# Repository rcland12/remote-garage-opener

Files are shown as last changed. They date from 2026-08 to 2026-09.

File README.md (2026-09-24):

# Remote garage door controller

Adds remote operation to a Linear garage door opener using an ESP32-S3 and an
optocoupler relay. The relay momentarily bridges the opener's pushbutton
terminals, exactly like pressing the wall button.

There is no door sensor. This is a remote wall button: it presses, and that is
all it does. It cannot tell you whether the door is open or closed, and it
does not pretend to. Use a camera in the garage for that, and look at it
before you press.

The device is LAN only. Reaching it from outside the house is a separate
service's job, and it is in this repo: `server/` is a small Python API that
holds the device token, authenticates every caller, and makes the LAN-local
call to the ESP32. Nothing routes to the controller from the internet.

That server runs on **Linux, macOS or Windows**, on whatever machine you
already leave switched on - a Raspberry Pi, a NAS, a mini PC, the old laptop
in the closet. It is one Python file with one optional dependency. There is a
Docker Compose stack, and a native install for each of the three platforms.
See `server/README.md`, and `docs/remote-access.md` for how to reach it from
outside.

## Quick start

    # 1. configure
    cp firmware/secrets.example.py firmware/secrets.py
    python3 -c "import secrets; print(secrets.token_urlsafe(32))"
    $EDITOR firmware/secrets.py

    # 2. flash MicroPython, then deploy       (docs/flashing.md)
    ./tools/deploy.sh --reset

    # 3. wire it up                            (docs/hardware.md)

    # 4. drive it
    export GARAGE_HOST=garage.home.arpa GARAGE_TOKEN=...
    ./tools/garage.py status
    ./tools/garage.py toggle

    # 5. optional: reach it from outside the house  (server/README.md)
    cd server && cp garage-api.env.example garage-api.env
    $EDITOR garage-api.env
    docker compose up -d --build

`DRY_RUN` in `firmware/config.py` gates whether the relay pin is driven at all.
It is currently `False`, because this build is commissioned and moving a real
door. Set it back to `True` before any bench work: with it on, `POST /toggle`
only writes a log line and the pin is never configured, so you can exercise
the whole API with the relay wired and nothing will move.

## API

The device's own API. The server in `server/` puts the same commands one hop
further out, namespaced under `/garage`, behind a credential you can revoke.

| Method | Path | Auth | Result |
|---|---|---|---|
| GET | `/health` | no | liveness, uptime |
| GET | `/status` | no | moving hint, uptime, RSSI, IP, reset cause |
| GET | `/log` | no | recent events from the in-memory ring buffer |
| POST | `/toggle` | yes | pulse the relay for 500 ms |

There is deliberately no `/open` or `/close`. Without a door sensor the device
cannot distinguish an open door from a closed one, so a "close" command would
be a coin flip that opens the garage half the time. One button, the same one
that is on the wall. Both paths return 404.

The `moving` field in `/status` is a timer counting down `TRAVEL_MS` from the
last pulse, not a measurement. It means "we pulsed recently, so the door is
probably still travelling." It is not evidence the door moved at all.

Auth is a shared secret in the `X-Auth-Token` header, compared in constant
time. Everything returns JSON with an `ok` field.

    curl -X POST -H "X-Auth-Token: $GARAGE_TOKEN" http://$GARAGE_HOST/toggle

A second pulse inside the cooldown window returns 429 rather than reversing a
door that just started moving.

## The server

`server/` is the other half of the build: a small API that fronts the device
so you can reach the door from outside the house without exposing anything.
It holds the device token, authenticates every caller, applies a per-caller
scope and a cooldown, and then makes the one LAN call the device understands.

    phone / laptop
      -> https://api.example.com/garage/toggle
      -> Cloudflare Access                  service token policy, at the edge
      -> cloudflared -> the server          on a machine in your house
      -> http://192.168.1.50/toggle         X-Auth-Token, LAN only
      -> the relay closes for 500 ms

**It runs anywhere.** One Python file, standard library only unless you use
Cloudflare Access, which adds PyJWT. Point it at a machine that stays on and
is on the same LAN as the ESP32 - a Raspberry Pi, a NAS, a mini PC, a desktop,
the laptop with the cracked screen. Pick an install:

| | Docker | Native |
|---|---|---|
| **Linux** | `docker compose up -d --build` | systemd unit, `sudo ./install/install-unix.sh` |
| **macOS** | Docker Desktop, same command | launchd daemon, same install script |
| **Windows** | Docker Desktop, same command | Scheduled Task, `.\install\install-windows.ps1` |

The native installs run at boot with no user logged in, which Docker Desktop
on macOS and Windows does not. On Linux either is fine.

Two ways to reach it, chosen with `AUTH_MODE`:

- **`access`** - a Cloudflare Tunnel and an Access service token policy. A
  real HTTPS URL with nothing port forwarded, and the only option an iPhone
  Shortcut can use, because a Shortcut cannot bring up a VPN first.
- **`token`** - no Cloudflare at all. Reach the machine over Tailscale,
  WireGuard or an SSH forward, and the server checks a bearer key per client
  on top of that.

| Method | Path | Result |
|---|---|---|
| POST | `/garage/toggle` | pulse the relay |
| POST | `/garage/selftest` | the same path, no pulse |
| GET | `/garage/status` | the device's status |
| GET | `/garage/log` | the device's event ring |
| GET | `/garage/audit` | who has pressed the button |
| GET | `/service/actions` | what these credentials may call |

Setup, per-OS notes, the Cloudflare dashboard steps and the iPhone Shortcut
recipes are all in `server/README.md`.

## Safety properties

These are the invariants the build is made of. Changing any of them should be
a deliberate decision, not a side effect of something else.

In the firmware:

- The relay pin is idle at boot, after a crash, and after a watchdog reset.
  It is initialised with `Pin(..., value=idle)` so there is no window where
  it is driven active.
- The relay only ever pulses. `Relay.poll()` releases it from the main loop;
  no code path can latch it on.
- GPIO 5 is a plain GPIO. Strapping pins 0, 3, 45 and 46 are never used.
- A hardware watchdog reboots a wedged board. The reboot cannot move the door.
- The only electrical connection to the opener is the isolated dry contact.
  Nothing touches the opener's 28 V supply.

In the server:

- `API_SCOPES` is deny by default, and empty is a fatal boot error. There is
  no safe permissive default for something that opens a garage door.
- `GARAGE_TOKEN` unset is deliberately not fatal. The service boots, the
  read-only routes work, and `/garage/toggle` refuses with a 502. Failing
  closed for a door means refusing to move it, not refusing to start.
- Nothing proxies a request through to the device. `device_call` hand-builds
  one with a single header, because the firmware's `MAX_REQUEST_BYTES` is
  2048 and a tunneled request is larger than that. Calls are serialised; the
  device serves one connection at a time.
- The device token never leaves the machine the server runs on. Clients hold
  a credential that can be revoked from a dashboard instead.
- The process is unprivileged, read-only, no volumes, no host paths, no
  capabilities. Every action it takes is one outbound HTTP call.

## Layout

    firmware/     MicroPython: config.py, garage.py, main.py, secrets.example.py
    server/       app.py             the API that fronts the device
                  run.py             start it from an env file, any OS
                  README.md          install, Cloudflare setup, troubleshooting
                  garage-api.env.example  every setting, with the reasoning
                  compose.yml        docker, with an optional cloudflared
                  Dockerfile         unprivileged, read-only, no volumes
                  install/           systemd, launchd, Windows scheduled task
                  cloudflared/       tunnel config example
    tools/        deploy.sh          push firmware to the board over USB
                  deploy.py          the same, cross-platform, and it names
                                     the UART bridge port by vendor id
                  garage.py          full client for both APIs: status, log,
                                     audit, actions, selftest, toggle, watch
                  toggle.sh          one-shot pulse, nothing else
                  verify_remote.sh   check the Cloudflare Access path end to end
                  smoke_test.sh      exercise every device endpoint
                  smoke_test.py      the same, without curl or bash
                  simulate.py        run the firmware on a desktop, no hardware
    docs/         hardware.md, flashing.md, remote-access.md
    enclosure/    build_enclosure.py  parametric Fusion 360 model, source of truth
                  *.stl               exported base and lid
    article/      medium-article.md   the writeup, not part of the build
                  medium-draft.md     the outline it came from
                  assets.md           shot list and pre-publish checklist

The `.py` tools are there so the build can be followed from Windows, where
neither bash nor curl is a given. They are standard library only and behave
identically to their shell counterparts; `garage.py` and `simulate.py` already
ran anywhere. Two implementations of the same check can drift, so if the shell
versions stop earning their keep, the Python ones are the better survivors.

## Testing without hardware

`tools/simulate.py` runs the real firmware on a desktop against stub hardware,
so the API, the auth path and the 500 ms pulse can all be exercised before the
parts are wired.

    ./tools/simulate.py --port 8099
    GARAGE_HOST=127.0.0.1:8099 GARAGE_TOKEN=simulator-token ./tools/smoke_test.sh --pulse

## Status

Deployed and in service. The controller sits on top of the opener's motor head
in its printed enclosure, wired to the `PUSHBUTTON` and `COMMON` terminals, and
moves the door on request.

Verified on the hardware, not just in simulation:

- 11/11 endpoint checks pass against the device
- Relay module is active HIGH; `RELAY_ACTIVE_HIGH = True`
- A 10k pull-down on GPIO 5 holds the relay off through the window between
  power-on and MicroPython configuring the pin. Confirmed silent across
  repeated resets and cold power-cycles, which is the test that matters
- Contact closes for roughly 500 ms per pulse, measured on a meter
- WiFi sits at -18 to -32 dBm in its installed position

Remote access is the Cloudflare Access path in `docs/remote-access.md`, served
by `server/` and driven from an iPhone Shortcut.

Outstanding: the enclosure has been revised since the installed one was
printed. The current STLs add a 180 degree ESP32 rotation so the USB ports
clear their guide wall, a wider and taller USB opening, a lid grip tongue, and
a looser slide fit. Reprint both parts when convenient; nothing is wrong with
the installed one.

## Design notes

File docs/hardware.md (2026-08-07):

# Hardware assembly

Build and wiring instructions for the remote garage controller. Work through
the steps in order. Steps 1 through 4 happen at a desk with nothing connected
to the opener, so a mistake costs you nothing.

## Safety

Read this once before starting.

- A garage door is the heaviest moving object in a house. It can injure a
  person or crush a car roof. Everything below assumes the opener's photo-eye
  safety sensors are installed and working. Test them before you commission
  this: wave a broom through the beam while the door is closing and confirm
  the door reverses. If it does not reverse, fix that before adding remote
  control.
- Unplug the opener from its ceiling outlet before touching its terminal
  screws. The motor and light circuit are line voltage.
- Operating a door you cannot see is the real risk this project introduces,
  and this build has no door sensor at all. It cannot tell you whether the
  door is open, let alone whether someone is standing in the doorway. A camera
  pointed at the garage is not optional here; it is the only feedback you get.
  Look at it before every remote operation.
- Nothing in this build connects to the opener's 28 V accessory supply. The
  only electrical connection to the opener is the isolated relay contact
  across the two pushbutton terminals.
- Route the low-voltage wiring away from the door's moving parts, the
  counterbalance springs and the chain or belt.

## Parts

| Item | Notes |
|---|---|
| ESP32-S3 dev board | Powered by USB from a 5 V phone charger |
| 1-channel relay module | 3.3 V trigger, optocoupler isolated, 3 V coil |
| Female-to-female Dupont jumpers | ESP32 to relay module, 3 needed |
| 470 uF electrolytic capacitor | Across relay VCC and GND, see step 2 |
| 16 AWG 2-conductor wire | Controller to opener terminals |
| USB cable and 5 V charger | Data-capable cable, you will flash over it |
| Multimeter | Needed for steps 2, 4 and 5. Not optional |
| Camera for the garage | Separate from this project, but do not skip it |

## Step 1: bench test the board, no relay attached

Flash MicroPython and the firmware first, following `docs/flashing.md`. Leave
`DRY_RUN = True` in `firmware/config.py` for now.

Power the board over USB, find its IP from the serial console, and confirm the
API answers:

    GARAGE_HOST=<ip> ./tools/smoke_test.sh

All read-only checks should pass. At this point `POST /toggle` only writes a
log line; the relay pin is never driven.

## Step 2: determine your relay module's trigger polarity

Most cheap optocoupler relay boards are active LOW: the relay energises when
IN is pulled to ground. Some are active HIGH. Get this right or the relay will
sit closed whenever the board is idle, which would hold the opener's button
down permanently.

With the relay module powered but its screw terminals connected to nothing:

1. Connect relay VCC to the ESP32 3V3 pin, relay GND to an ESP32 GND pin.
2. Leave relay IN disconnected. Note whether the relay's LED is on and whether
   you heard it click when power was applied.
3. Touch the IN pin briefly to GND. If the relay clicks in, it is active LOW.
4. Touch IN briefly to 3V3. If it clicks in, it is active HIGH.

Set `RELAY_ACTIVE_HIGH` in `firmware/config.py` accordingly.

Measured on this build: the module is a Songle SRD-03VDC-SL-C board with screw
terminal inputs rather than a pin header, and it is **active HIGH**. IN to 3V3
energises it, IN to GND does nothing. `RELAY_ACTIVE_HIGH = True` is set.

Active HIGH carries a boot risk that active LOW does not. Idle is a LOW pin,
but from power-on until MicroPython configures GPIO 5, that pin is an
undriven input and floats. A pin floating high is a relay clicking on boot,
which is a garage door opening during a thunderstorm. Step 4 tests for this
explicitly. If it fails, fit a 10k resistor from GPIO 5 to GND, which holds IN
low through the float window without affecting the firmware's ability to drive
it high.

While you are here, check the coil voltage printed on the relay can. Match the
supply to the coil; this goes wrong in both directions.

- Coil says 5 V: power VCC from the dev board's 5V (VBUS) pin, not 3V3, and
  leave IN on GPIO 5. The optocoupler input still triggers happily from 3.3 V.
  A 5 V coil on the 3V3 regulator will brown out the board.
- Coil says 3 V or 3.3 V: power VCC from 3V3. Do not "fix" a brownout by
  moving it to 5V, which puts roughly 65 percent over-voltage across a 3 V
  coil. See the capacitor note below instead.

A 3 V coil draws on the order of 100 to 150 mA while energised, and it pulls
that current in a step. The dev board's regulator can supply it, but the
inrush lands on the same 3V3 rail the radio uses. Fit a bulk capacitor,
100 uF or larger electrolytic, directly across the relay module's VCC and GND
pins, minding polarity. That is cheap insurance against a reset when the relay
fires and it costs nothing if the rail was fine anyway.

You do not need to add a flyback diode. These optocoupler modules already have
one across the coil, along with the driver transistor.

## Step 3: wire the relay to the ESP32

Unplug USB power first.

| ESP32-S3 pin | Relay module pin |
|---|---|
| 3V3 (or 5V, see step 2) | VCC |
| GND | GND |
| GPIO 5 | IN |

GPIO 5 is a plain GPIO on the ESP32-S3. Do not move the relay to GPIO 0, 3, 45
or 46. Those are strapping pins; they are sampled and can glitch at reset,
which would pulse the door every time the board reboots.

If your relay module has a separate JD-VCC jumper, leave the factory jumper in
place. That jumper is what shares the logic supply with the coil, which is
what you want for a single-supply build.

## Step 4: verify the pulse, still not connected to the opener

Set `DRY_RUN = False` in `firmware/config.py`, redeploy, and put a multimeter
in continuity or resistance mode across the relay's COM and NO screw
terminals. It should read open circuit.

Fire a pulse:

    GARAGE_HOST=<ip> GARAGE_TOKEN=<token> ./tools/garage.py toggle

You should hear one click, see the relay LED flash, and the meter should beep
for about half a second before going open again. Confirm all three:

- Exactly one click in, one click out. Never a latch.
- `GET /log` shows a single `relay_pulse` entry.
- Press the board's reset button. The relay must not click at all during
  boot. Do not proceed to step 5 until a reset is silent.
- Pull the USB cable and plug it back in. Same requirement: no click. A cold
  power-up is a different case from a reset button, because the 3V3 rail is
  ramping at the same time the pin is floating. Test both.

If a reset does click, this build is active HIGH and the cause is almost
certainly GPIO 5 floating before the firmware drives it. Fit a 10k resistor
between GPIO 5 and GND. It holds IN low through the float window and is far
too weak to interfere with the firmware driving the pin high afterwards.
Re-run both tests before continuing.

## Step 5: identify the opener's pushbutton terminals

Unplug the opener.

The Linear opener has a low-voltage terminal strip on the back or side of the
motor head, where the wall button wires land. Some Linear wall stations use
two wires, some use three (the third drives the light). You want the two
terminals that the existing wall button's switch contacts bridge.

Confirm with the multimeter before you connect anything:

1. Plug the opener back in. Do not touch the line-voltage side.
2. Measure DC voltage across the candidate pair. Expect something in the
   region of 5 to 24 V open circuit. This is the opener sensing an open
   switch.
3. If you measure around 28 V, you are on the accessory supply pair. Move off
   it. Nothing in this project touches that.
4. Have someone press the wall button, or briefly bridge the pair with a short
   jumper wire. The door should run. That confirms the pair, and it confirms
   that a dry contact is all the opener wants.

Unplug the opener again once you have identified the pair.

## Step 6: connect the relay to the opener

Run the 16 AWG two-conductor wire from the controller's location to the
opener's terminal strip. 16 AWG is far heavier than this signal needs, which
is fine; it just makes the screw terminals a little crowded.

| Relay screw terminal | Opener terminal |
|---|---|
| COM | one of the pushbutton pair |
| NO | the other of the pushbutton pair |

Polarity does not matter. This is a dry contact, exactly equivalent to the
wall button's own switch. Leave the existing wall button wired in parallel;
both will keep working.

Do not use the NC terminal. NC is closed at rest, which would hold the
opener's button pressed.

## Step 7: the camera

This build has no door sensor, so the API cannot tell you whether the door is
open or closed. A camera in the garage is what fills that gap, and it fills it
better than a reed switch would: it shows you the doorway, not just the door.

Set it up before you start operating the door remotely, not after. It does not
need to integrate with this project in any way. It needs to be something you
can pull up on your phone, in a second or two, from wherever you are.

The habit that makes this safe is: look, then press. A reed switch could never
have told you a bicycle was leaning in the doorway.

## Step 8: commissioning

1. Power the controller from the 5 V phone charger, not from a laptop.
2. Stand where you can see the door.
3. `./tools/garage.py status`, confirm the API answers.
4. `./tools/garage.py toggle`, confirm the door runs.
5. Let it finish. Confirm `moving` clears about 15 seconds later.
6. Reset the board while the door is closed. Confirm the door does not move.
7. Pull the charger and plug it back in. Confirm the door does not move, and
   that the API comes back on its own within about 30 seconds.

Steps 6 and 7 are the ones that matter. A controller that pulses the door on
power-up is a controller that opens your garage during a thunderstorm.

Then repeat step 4 once from outside the house, over the VPN, with the camera
up on your phone. That is the real workflow; run it once while you are still
close enough to walk back and fix things.

## Cable strain relief

Anchor both cables so a tug lands on a zip tie and not on a solder joint or a
Dupont pin: the USB cable and the pair going to the opener.

The printed enclosure has an anchor tab outside each cable exit, with a pair of
slots through it. Thread a tie up through one slot, over the cable, and down
through the other. Both tabs sit at the floor line, flush with the bottom face,
so they do not interfere with the adhesive strips.

Anchoring to a nearby joist or the opener's rail bracket also works, and is
worth doing as well as the tabs for the run to the opener terminals, which is
the longer and more exposed of the two.

## Troubleshooting

| Symptom | Likely cause |
|---|---|
| Relay clicks once at every boot | Trigger polarity wrong, or relay moved to a strapping pin. Recheck step 2 |
| Relay clicks but the door does nothing | Wrong terminal pair, or wired to NC instead of NO |
| Door runs twice per request | `PULSE_MS` too long for this opener, try 300 ms |
| `POST /open` returns 404 | Correct. There is no door sensor, so only `/toggle` exists. See the README |
| API unreachable after a few days | Check `GET /status` for `reset_cause`. `watchdog` means the loop wedged and recovered |
| Board reboots when the relay fires | Coil inrush is browning out the 3V3 rail. Add the bulk capacitor from step 2. Only move VCC to 5V if the coil is actually rated 5 V |

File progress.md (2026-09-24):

# Progress

State of the build. Written down because the useful parts are the decisions
and the measurements, not the code, and neither is recoverable from a diff.

## Where it is

Deployed and in service. The controller sits on top of the opener's motor
head, wired to the `PUSHBUTTON` and `COMMON` terminals, and moves the door.

## Firmware

Three files plus a secrets template, MicroPython 1.28.0 on an ESP32-S3.

- `main.py` - WiFi with auto-reconnect, HTTP API, one cooperative loop. The
  listening socket is polled with a 20 ms timeout so servicing the relay and
  the watchdog never waits on a client, and no client waits on a 500 ms pulse.
- `garage.py` - relay pulse state machine and the event ring buffer.
- `config.py` - pins, timings, `DRY_RUN`, relay polarity.

Four routes: `GET /health`, `GET /status`, `GET /log`, `POST /toggle`.

There is no `/open` or `/close`. There was, early on, and they read a reed
switch to decide whether to no-op. Both are gone along with the reed switch
itself. Without a sensor those endpoints can only guess, and a wrong guess on
`/close` opens the garage and leaves it open.

Worth knowing about the removal: with the reed switch gone but the endpoints
still present, `/open` would have returned `"ok": true, "action": "none"` and
never pulsed the relay, because the unconnected pin read as "already open"
forever. `tools/smoke_test.sh` only exercised `/toggle`, so it passed 9/9 while
`/open` was silently dead. The smoke test now asserts both paths return 404.

## Hardware

| Item | Value |
|---|---|
| Board | ESP32-S3 N16R8, 16 MB flash, 8 MB octal PSRAM |
| Bridge chip | CH343 (`1a86:55d3`), enumerates as `/dev/ttyACM0` |
| Relay | Songle SRD-03VDC-SL-C module, screw terminal inputs |
| Trigger polarity | **Active HIGH**, measured |
| Pull-down | 10k, GPIO 5 to GND |

Two things here cost real time and are worth remembering.

**The board has two USB-C ports, `COM` and `USB`.** Use `COM`. It is the UART
bridge, its DTR/RTS drive EN and GPIO 0, so esptool enters the bootloader on
its own and the port survives whatever the firmware does. Do not identify it
by device name: this board's CH343 is a CDC-class part, so `COM` appears as
`ttyACM0`, the same name native USB would use. Tell them apart by USB vendor
id, `1a86` for the bridge and `303a` for Espressif.

**The relay is active HIGH, which is the uncommon case.** Idle is therefore a
LOW pin, and between power-on and MicroPython configuring GPIO 5 that pin is
an undriven input that floats. A pin floating high is a relay clicking on
boot, which is a garage door opening during a thunderstorm. The 10k pull-down
exists for exactly that window. It was fitted before testing rather than after,
because whether a floating pin drifts high enough depends on temperature and
humidity, and passing three resets on a desk in July proves nothing about a
cold morning in January.

## Enclosure

Parametric Fusion 360 model, driven over an SSH tunnel through the fusion360
MCP bridge. `enclosure/build_enclosure.py` is the source of truth; it is
idempotent and rebuilds everything from its parameter table.

Both boards are retained by their edges, not screwed down: neither has usable
mounting holes. Rails support the PCB edges, guide walls locate them
laterally, and a sliding lid closes it.

Decisions that are not obvious from the geometry:

- **The ESP32 faces component-side down.** The Dupont wires must reach the
  pins, so the pins point up. The cost is that its LED, reset and BOOT buttons
  face the floor and are unreachable once assembled. Acceptable because
  flashing happens over `COM` with auto-reset.
- **The ESP32 is rotated 180 degrees** from the arrangement you would first
  reach for. The guide wall has to bear on one end of the board, and against
  the USB end it blocks the ports. Against the antenna end it does not. This
  also puts the USB cable on the same side as the wall outlet.
- **The antenna keep-out was relaxed from 20 mm to 10 mm** to shorten the box.
  Measured RSSI in the installed position is -18 to -32 dBm, roughly 50 dB of
  margin, so this is not close to mattering. If range ever looks marginal,
  widen `board_gap` or put the keep-out back.
- **Vented rather than sealed.** South Georgia: hot, very humid. A sealed but
  non-waterproof box breathes through its seams as temperature swings and
  accumulates condensation with no way out. Vents low on one wall and high on
  the opposite drive convection. Weep slots sit at the floor line because a
  box lying flat cannot drain downward.

The installed enclosure predates the 180 degree rotation, the enlarged USB
opening, the lid grip tongue and the looser slide fit. Reprint when convenient.

## Remote access

Cloudflare Tunnel plus an Access-gated API, driven from an iPhone Shortcut.
The device's own posture is unchanged and must stay that way: LAN only, plain
HTTP, one shared token, nothing routed to it from outside.

The server holds `API_TOKEN`; the phone holds only Cloudflare service token
credentials, which are revocable from the dashboard in seconds. Losing the
phone does not mean reflashing the ESP32.

**That server now lives in this repo, at `server/`.** It was one area of a
larger multi-purpose endpoint on the owner's own server; the garage part was
lifted out into a standalone service so the build is complete in one place -
until now, following this repo got you a controller you could only reach from
the LAN, with the other half described but not shipped. Decisions made in the
move:

- **Only the garage area came across.** The original also fronted a passcode
  endpoint, fail2ban unbans and AI usage counters. None of that belongs here
  and none of it was copied.
- **A second auth mode, `AUTH_MODE=token`.** The original assumed Cloudflare
  Access, which assumes a domain and a Zero Trust account. `docs/remote-access.md`
  has always listed Tailscale as the recommended option, so the service now
  accepts a per-client bearer key for the deployments where there is no
  Cloudflare in the path. `access` is still the default.
- **No nginx.** Upstream, nginx did the path allowlisting and rate limiting.
  With five routes and an app that 404s everything else, the allowlist is
  redundant; the rate limit moved in-process. One less thing to install on
  whatever machine is going to run this.
- **Native installs for all three platforms, not just Docker.** Docker
  Desktop on macOS and Windows starts at login, not at boot, which is the
  wrong behaviour for a service that has to answer when nobody is home. The
  systemd unit, the launchd daemon and the Windows scheduled task all start
  without a session.
- **`tools/garage.py` and `tools/verify_remote.sh` learned the namespaced
  paths.** The upstream API puts everything under `/garage/*`; the client was
  still asking the tunnel for `/status`. `garage.py` also picked up
  `GARAGE_API_KEY` for token mode and an `actions` command.

`tools/verify_remote.sh` checks that path end to end without moving the door.
It has one blind spot it reports honestly: the controller's only
token-checked route is the one that pulses the relay, so nothing can confirm
`GARAGE_TOKEN` is correct without opening the garage. After rotating it, the
first `/toggle` is the test, and it is one to run standing in the garage.

## Standing constraints

- Camera first, every time. The device cannot tell you which way the door will
  go, and it cannot tell you whether anyone is standing in the doorway.
- Do not automate `/toggle`. A schedule or a geofence has no idea what the
  door is doing, and the failure mode is an open garage you find out about
  when you get home.
- Test the opener's photo-eye sensors periodically. Operating a door you
  cannot see makes them the only thing protecting the doorway.

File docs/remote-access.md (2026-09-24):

# Reaching the door from outside the house

The device itself is deliberately dumb about the internet: LAN only, plain
HTTP, one shared token. That posture is only safe because nothing routes to it
from outside. This document covers how to close that gap without ever port
forwarding to the ESP32.

Do not port forward to the controller. It has no TLS, no rate limiting and no
firmware update path. A single leaked token would be an open garage.

## The shape

    phone / laptop  --VPN or Access-->  local server (LAN)  --HTTP-->  ESP32
      anywhere                                                          garage

The local server is the only thing that talks to the controller. It is already
on the LAN and you already reach it over SSH, so it does the authenticating
and the exposing. `server/` in this repo is that piece: one Python file, with
a Docker stack and native installs for Linux, macOS and Windows. It does not
care which of the options below you pick - A, B and C need nothing from it but
`AUTH_MODE=token`, and D is `AUTH_MODE=access`.

Option D is what is deployed. A and B remain the fallbacks for when the
tunnel, the Cloudflare account or the server is the thing that is broken.

## Option A: Tailscale, recommended

Install Tailscale on the local server and on your phone and laptop. The
controller stays untouched.

    curl -fsSL https://tailscale.com/install.sh | sh
    sudo tailscale up

Now from anywhere:

    ssh you@server-name
    GARAGE_HOST=garage.home.arpa GARAGE_TOKEN=... ~/garage/tools/garage.py toggle

To skip the SSH step, run `server/` in token mode and bind it to the tailnet
address. Set `AUTH_MODE=token` and an `API_CLIENTS` entry per device, then:

    BIND_ADDR=$(tailscale ip -4) docker compose up -d

    export GARAGE_HOST=http://server-name.your-tailnet.ts.net:8080
    export GARAGE_API_KEY=...
    ./tools/garage.py toggle

Reachable only by devices you have authorised, and the key is still required
on top of that, so a compromised tailnet device is not automatically a
compromised garage. Revoking one device's key does not disturb the others,
and neither touches the ESP32.

`tailscale serve --bg --https=443 http://127.0.0.1:8080` in front of it adds
TLS terminated by Tailscale, if you would rather the key did not travel over
plain HTTP even inside the tunnel.

Do not use `tailscale funnel` here. Funnel publishes to the public internet.

## Option B: WireGuard

Same shape, more setup, no third party. Stand up WireGuard on the local
server, route your LAN subnet to VPN clients, and connect before using the
client tool. Once connected, the controller is just another LAN address.

## Option C: SSH port forward, zero extra software

Good enough if you only ever act from a laptop:

    ssh -L 8080:192.168.1.50:80 you@server
    GARAGE_HOST=127.0.0.1:8080 GARAGE_TOKEN=... ./tools/garage.py status

This one forwards straight to the device, so it needs no server at all - the
SSH login is the authentication and `GARAGE_TOKEN` is the device's own. Forward
to the server instead if you would rather the scopes and the audit log
applied:

    ssh -L 8080:127.0.0.1:8080 you@server
    GARAGE_HOST=http://127.0.0.1:8080 GARAGE_API_KEY=... ./tools/garage.py status

## Option D: Cloudflare Access, deployed

This is the path an iPhone Shortcut can use, because a Shortcut cannot bring
up a VPN first. It gets a real HTTPS URL without port forwarding anything: the
tunnel is an outbound connection from the server, so the LAN keeps no inbound
holes.

    iPhone Shortcut
      -> https://api.example.com/garage/toggle   CF-Access-Client-Id + -Secret
      -> Cloudflare Access                        service token policy, edge
      -> cloudflared -> the server                on a machine in the house
      -> http://192.168.1.50/toggle                X-Auth-Token
      -> relay closes for 500 ms

The server lives in this repo at `server/`; `server/README.md` has the build
and the Zero Trust dashboard setup. Two things about it matter from this side:

- **The device token never leaves the server.** The phone holds Cloudflare
  service token credentials, which can be revoked from the Zero Trust
  dashboard in seconds. It never holds `API_TOKEN`. Losing the phone does not
  mean re-flashing the ESP32.
- **The device never sees a tunneled request.** `MAX_REQUEST_BYTES` is 2048
  and a Cloudflare request with an Access assertion on it is bigger than that.
  The server throws all of it away and sends the controller three lines.

### The iPhone Shortcut

Shortcuts app > new shortcut > Get Contents of URL:

    URL     https://api.example.com/garage/toggle
    Method  POST
    Headers CF-Access-Client-Id      <client id>.access
            CF-Access-Client-Secret  <client secret>

Add a display action after it so a failure is visible rather than silent. A
shortcut with no display action run from the Home Screen finishes without
saying anything, which is the wrong behaviour for a door. Use **Quick Look**
while testing, since it shows the raw JSON, and **Show Notification** on the
real one, since a banner beats a full-screen takeover. (Older guides say
"Show Result"; that name is from the Workflow era and is not dependable in
current Shortcuts. Action names move between iOS versions, so search rather
than trusting any exact name here.)
Add it to the home screen if you want, but see the warning below about what a
one-tap door button on a lock screen means.

**Build it against `/garage/selftest` first.** Same method, same headers, same
route through Access and the tunnel and the server to the controller, minus
the pulse. Get a `{"ok": true, "action": "garage.selftest"}` back, then change
the URL to `/garage/toggle` once and never touch it again.

    ./tools/garage.py selftest      # the same check from the server

Run it after a router or DHCP change, or any time you want to know the remote
path is intact without finding out the hard way.

It has one blind spot, and it reports it as `device_token_verified: false`.
The controller's unauthenticated routes answer the same whether the shared
token is right or wrong, and its only token-checked route is the one that
moves the door, so **`/garage/selftest` cannot tell you `GARAGE_TOKEN` is
correct.**
After rotating that token the first `/toggle` is the test, and it is the kind
of test you want to run standing in the garage rather than from a car.

The firmware has no endpoint to close that gap on purpose. The device lives
inside the opener head in a rental; adding a route means taking it down to
reflash it, which is too much for a check that only matters on the day you
rotate a token.

To confirm the gate is actually closed, run the same request with the headers
removed. It must come back as a Cloudflare login page, never as JSON:

    curl -sS -o /dev/null -w '%{http_code}\n' https://api.example.com/garage/status

### What this does and does not buy you

It closes the network problem: nothing on the public internet reaches the
controller, and the credential that does reach it is revocable and logged, at
the edge by Cloudflare and locally by the server at `GET /garage/audit`.

It does not close the problem in the next section. A URL that opens the garage
from anywhere is still a `/toggle`, and it still cannot tell you which way the
door will go. Making the button easier to press does not make it smarter.

Concretely: the service token sits in the Shortcut on the phone. Anyone with
the unlocked phone has the garage. That is the same trust as a clipped-on
remote in the car, which is worth saying out loud because an HTTPS endpoint
with a signed JWT in front of it can feel like more security than it is.

## Pin the device's address

Whichever option you pick, give the ESP32 a fixed address so the host name in
your scripts stays valid. Either reserve its MAC in the router's DHCP table,
which is the tidier option, or set `STATIC_IP` in `firmware/secrets.py`:

    STATIC_IP = ("192.168.1.50", "255.255.255.0", "192.168.1.1", "192.168.1.1")

## Keeping the token honest

- The token lives in `firmware/secrets.py` on the device and in
  `server/garage-api.env` on the server. Both are gitignored. Nowhere else,
  and never on a phone.
- Rotate it by editing `secrets.py`, redeploying, updating `GARAGE_TOKEN` in
  `garage-api.env` and restarting the server - `docker compose up -d`, not
  `restart`, because a container's environment is fixed at creation. The
  Cloudflare service token rotates independently, in the dashboard, and needs
  no change on the device.
- Every rejected request is logged. `GET /log` showing `auth_fail` entries you
  did not cause means something on your LAN is probing the device.
- `GET /status`, `/health` and `/log` are unauthenticated by design, so a
  monitoring check does not need the secret. They cannot move the door, and
  they carry no door state to leak. If you would rather not expose uptime and
  SSID to the LAN, add the same `token_ok` check to those routes in
  `firmware/main.py`.

## /toggle is the only door command

`POST /toggle` presses the button, exactly like the wall switch: if the door
was moving it stops, if it was stopped it reverses. When you are not standing
there, that is a coin flip.

There is no `/open` or `/close` to prefer instead. This device has no door
sensor, so it cannot know which way a pulse will send the door. Endpoints that
claimed otherwise would be guessing, and a wrong guess on `/close` opens your
garage and leaves it open.

The consequence is that **you have to resolve the ambiguity yourself, before
you press.** Pull up the garage camera, see which way the door is, then
toggle. Do not automate this. A script that fires `/toggle` on a schedule or a
geofence has no idea what it is doing, and the failure mode is an open garage
you do not find out about until you get home.

Nothing on the device can tell you the doorway is clear either. That is also
what the camera is for.

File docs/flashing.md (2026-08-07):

# Flashing and deploying

One-time MicroPython install, then a two-second deploy loop for firmware
changes.

## Host setup

    source ~/.global_venv/bin/activate
    pip install esptool mpremote

On Linux your user needs serial access:

    sudo usermod -aG dialout $USER      # log out and back in

### On Windows

Install Python from python.org with "Add Python to PATH" ticked, then
`pip install esptool mpremote` as above. Ports are `COM3`, `COM5` and so on;
there is no group to join. If PowerShell refuses to activate a venv, that is
the execution policy: `Set-ExecutionPolicy -Scope CurrentUser RemoteSigned`.

Use `tools/deploy.py` and `tools/smoke_test.py` rather than the `.sh`
versions. They are standard library only and take the same arguments.

Do not flash from inside WSL. WSL2 cannot see a USB serial device without
`usbipd-win` and an elevated re-attach on every replug, and this board gets
unplugged a lot during bring-up. Run the tools in native Windows.

Note that in Windows PowerShell 5.1 `curl` is an alias for `Invoke-WebRequest`
and takes entirely different arguments. Any `curl` line in these docs needs to
be `curl.exe`, or use the Python tools instead.

## Which USB port

Dev boards with two USB-C ports label them `COM` and `USB`. They are not
interchangeable:

- `COM` goes to the USB-to-UART bridge chip. Its DTR and RTS lines drive GPIO 0
  and EN, which is what lets esptool enter the ROM bootloader on its own. It
  stays enumerated no matter what the firmware does.
- `USB` goes to the S3's native USB peripheral on GPIO 19 and 20. It can flash,
  but there is no auto-reset circuit, so a wedged firmware means holding BOOT
  and tapping RESET by hand. It also drops off the host whenever the running
  firmware reconfigures USB.

Use `COM`. This firmware arms a watchdog and reboots itself, so the port that
survives reboots is the one you want.

## Find the port

Plug the board in and check:

    ls /dev/ttyACM* /dev/ttyUSB* 2>/dev/null

Do not identify the port by its device name. Whether a port appears as
`ttyACM*` or `ttyUSB*` depends on the bridge chip's USB class, not on which
of the two ports it is:

- CH343 and other CDC-class bridges bind to `cdc_acm` and appear as
  `/dev/ttyACM0`, the same name native USB uses.
- CH340 and CP210x need vendor drivers and appear as `/dev/ttyUSB0`.

Use the USB vendor ID to tell them apart:

    lsusb

    1a86:...    QinHeng/WCH bridge chip  -> this is the COM port
    10c4:...    Silicon Labs CP210x      -> this is the COM port
    303a:...    Espressif                -> this is the native USB port

If nothing appears at all, the cable is charge-only; swap it for a data cable.

The board this repo was built against is a CH343 bridge, `1a86:55d3`, and its
COM port enumerates as `/dev/ttyACM0`.

If the board is already running something that grabs the USB peripheral, hold
BOOT, tap RESET, then release BOOT to force the ROM bootloader.

## Install MicroPython

Download the current stable `.bin` for the `ESP32_GENERIC_S3` board from
<https://micropython.org/download/ESP32_GENERIC_S3/>. If your board has 8 MB
of octal SPIRAM, take the SPIRAM_OCT variant; the plain build is the safe
default and this firmware needs almost no RAM either way.

Ask the chip which one it is before downloading:

    esptool --chip esp32s3 --port /dev/ttyACM0 flash-id

Read the `Features` and `Detected flash size` lines. 8 MB of embedded PSRAM
means an octal part, so take SPIRAM_OCT; the 2 MB quad-PSRAM modules and the
no-PSRAM boards take the plain build.

The board this repo was built against reports 16 MB flash and `Embedded PSRAM
8MB`, an N16R8 module, running `ESP32_GENERIC_S3-SPIRAM_OCT` v1.28.0. After
boot it reports roughly 8.3 MB of free heap, which confirms PSRAM came up.

    esptool --chip esp32s3 --port /dev/ttyACM0 erase-flash
    esptool --chip esp32s3 --port /dev/ttyACM0 --baud 460800 \
        write-flash -z 0 ESP32_GENERIC_S3-<version>.bin

Note the flash offset is `0`, not the `0x1000` used by the original ESP32.

esptool v4 and older spell the subcommands with underscores (`erase_flash`,
`write_flash`) and install as `esptool.py`. Both spellings work on v5.

Confirm you have a REPL:

    mpremote connect /dev/ttyACM0 repl

You should get a `>>>` prompt. Ctrl-] exits.

## Configure

    cp firmware/secrets.example.py firmware/secrets.py
    python3 -c "import secrets; print(secrets.token_urlsafe(32))"

Put the WiFi SSID, WiFi password and that generated token into
`firmware/secrets.py`. It is gitignored; keep it that way.

Leave `DRY_RUN = True` in `firmware/config.py` until the wiring has been
verified through step 4 of `docs/hardware.md`.

## Deploy

    ./tools/deploy.sh                    # auto-detect port
    ./tools/deploy.sh /dev/ttyACM0       # explicit
    ./tools/deploy.sh --reset            # deploy, reboot, open the console

Or the cross-platform equivalent, which additionally applies the vendor-id
rule above rather than making you run `lsusb` yourself:

    python tools/deploy.py --list             # candidate ports, bridge first
    python tools/deploy.py --port /dev/ttyACM0
    python tools/deploy.py --port COM5 --reset

The script refuses to run if `secrets.py` is missing or still holds the
placeholder token, and reminds you when `DRY_RUN` is on.

Equivalent by hand:

    mpremote connect /dev/ttyACM0 fs cp firmware/config.py :config.py
    mpremote connect /dev/ttyACM0 fs cp firmware/garage.py :garage.py
    mpremote connect /dev/ttyACM0 fs cp firmware/main.py :main.py
    mpremote connect /dev/ttyACM0 fs cp firmware/secrets.py :secrets.py
    mpremote connect /dev/ttyACM0 reset

`main.py` runs automatically at boot. The serial console prints every event
that `GET /log` returns, which is how you read the device's IP address the
first time:

    mpremote connect /dev/ttyACM0 repl

    [     0s] boot reset=power-on dry_run=True
    [     0s] wifi_connect your-ssid
    [     2s] wifi_up 192.168.1.50
    [     2s] http_up port 80

## Stopping the firmware to get a clean REPL

The main loop runs forever and arms a watchdog, so a plain Ctrl-C at the REPL
gets interrupted by the next reboot. To work interactively, either set
`WDT_ENABLED = False` in `config.py` and redeploy, or interrupt and
immediately remove `main.py`:

    mpremote connect /dev/ttyACM0 fs rm :main.py

The watchdog cannot be disabled at runtime once started; that is a hardware
property of the ESP32, and it is the behaviour we want in service.

## Testing without hardware

`tools/simulate.py` runs the real `firmware/main.py` on your desktop against
stub `machine` and `network` modules. Useful for changing the API without
touching the board:

    ./tools/simulate.py --port 8099

    # in another shell
    GARAGE_HOST=127.0.0.1:8099 GARAGE_TOKEN=simulator-token \
        ./tools/smoke_test.sh --pulse

The simulator prints every relay pin transition with a timestamp, so you can
confirm pulse width without a scope. A healthy run shows the pin going to its
active level and back roughly 500 ms later, and nothing else touching a pin.

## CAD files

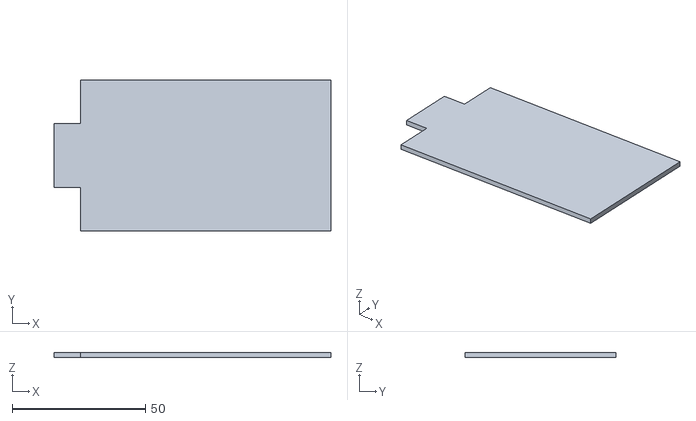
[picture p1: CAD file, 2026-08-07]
enclosure/remote-garage-opener v11_enclosure_lid.stl
104.1 x 56.7 x 2.00

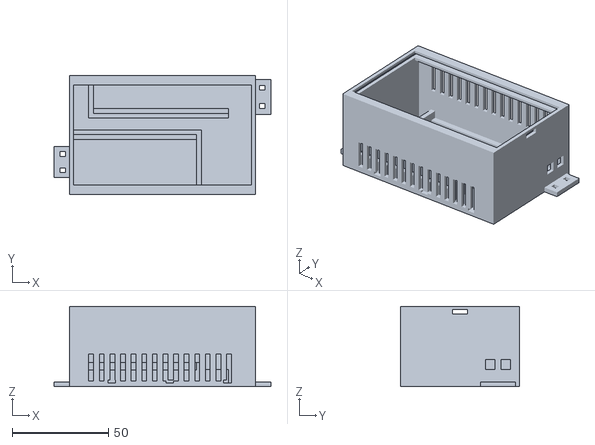
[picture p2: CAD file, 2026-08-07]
enclosure/remote-garage-opener v11_enclosure_base.stl
112.5 x 61.6 x 41.6

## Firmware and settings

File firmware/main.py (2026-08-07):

"""Remote garage door controller: WiFi, HTTP API and the main service loop.

Design notes:
  - One cooperative loop. The listening socket is polled with a short timeout,
    so servicing the relay and the watchdog never waits on a client, and a
    client never waits on a 500 ms relay pulse.
  - The relay is idle at boot and after any reset, crash or watchdog reboot.
  - Everything that changes the door requires the shared secret token.
  - There is no door sensor. This device pulses the opener's pushbutton and
    reports nothing about the door's position, because it cannot know it.
    POST /toggle is therefore the only door command, matching the single
    button on the wall. Look at the garage camera before using it.
"""

import gc
import json
import select
import socket
import sys
import time

import config
import machine
import network
from garage import EventLog, Relay

try:
    import secrets
except ImportError:
    print(
        "FATAL: secrets.py is missing. Copy secrets.example.py and fill it in."
    )
    raise SystemExit


# --- Monotonic clock --------------------------------------------------------
# time.ticks_ms() wraps roughly every 12 days on MicroPython. Accumulate the
# deltas so uptime and every deadline in the program keep working past that.

_last_tick = time.ticks_ms()
_uptime_ms = 0


def uptime_ms():
    global _last_tick, _uptime_ms
    now = time.ticks_ms()
    _uptime_ms += time.ticks_diff(now, _last_tick)
    _last_tick = now
    return _uptime_ms


# --- Globals ----------------------------------------------------------------

log = EventLog(config.LOG_SIZE)
relay = Relay(log)
wdt = None
wlan = None
_moving_until = 0
_next_wifi_check = 0


# --- WiFi -------------------------------------------------------------------

# Built with getattr so a port that is missing one of these constants gives a
# vaguer log line rather than an ImportError, which here would be a boot loop.
RESET_CAUSES = {}
for _name, _label in (
    ("PWRON_RESET", "power-on"),
    ("HARD_RESET", "hard"),
    ("WDT_RESET", "watchdog"),
    ("SOFT_RESET", "soft"),
    ("DEEPSLEEP_RESET", "deepsleep"),
):
    _code = getattr(machine, _name, None)
    if _code is not None:
        RESET_CAUSES[_code] = _label


def wifi_start():
    global wlan
    wlan = network.WLAN(network.STA_IF)
    wlan.active(True)
    try:
        # Keep the radio out of power save so the API stays responsive.
        wlan.config(pm=network.WLAN.PM_NONE)
    except (AttributeError, ValueError, OSError):
        pass
    static = getattr(secrets, "STATIC_IP", None)
    if static:
        wlan.ifconfig(static)
    return wlan


def wifi_connect(timeout_ms=30000):
    """Attempt to associate. Returns True on success. Feeds the watchdog."""
    if wlan.isconnected():
        return True
    log.add("wifi_connect", secrets.WIFI_SSID, uptime_ms())
    try:
        wlan.connect(secrets.WIFI_SSID, secrets.WIFI_PASSWORD)
    except OSError as exc:
        log.add("wifi_error", str(exc), uptime_ms())
        return False

    deadline = uptime_ms() + timeout_ms
    while uptime_ms() < deadline:
        feed()
        if wlan.isconnected():
            log.add("wifi_up", wlan.ifconfig()[0], uptime_ms())
            return True
        time.sleep_ms(200)
    log.add("wifi_timeout", None, uptime_ms())
    return False


def wifi_poll(now):
    """Re-associate after a drop, without blocking the loop for long."""
    global _next_wifi_check
    if now < _next_wifi_check:
        return
    _next_wifi_check = now + config.WIFI_RETRY_MS
    if not wlan.isconnected():
        log.add("wifi_down", None, now)
        wifi_connect(timeout_ms=8000)


def rssi():
    try:
        return wlan.status("rssi")
    except (OSError, ValueError, TypeError):
        try:
            return wlan.config("rssi")
        except Exception:
            return None


def ip_address():
    try:
        return wlan.ifconfig()[0]
    except Exception:
        return None


# --- Watchdog ---------------------------------------------------------------


def feed():
    if wdt is not None:
        wdt.feed()


# --- HTTP -------------------------------------------------------------------

STATUS_TEXT = {
    200: "OK",
    400: "Bad Request",
    401: "Unauthorized",
    404: "Not Found",
    405: "Method Not Allowed",
    409: "Conflict",
    413: "Payload Too Large",
    429: "Too Many Requests",
    500: "Internal Server Error",
}


def send_json(conn, code, payload):
    body = json.dumps(payload).encode()
    head = (
        "HTTP/1.1 %d %s\r\n"
        "Content-Type: application/json\r\n"
        "Content-Length: %d\r\n"
        "Cache-Control: no-store\r\n"
        "Connection: close\r\n\r\n"
        % (code, STATUS_TEXT.get(code, "OK"), len(body))
    )
    conn.send(head.encode())
    conn.send(body)


def read_request(conn):
    """Return (method, path, headers). Raises ValueError on a bad request."""
    buf = b""
    while b"\r\n\r\n" not in buf:
        chunk = conn.recv(256)
        if not chunk:
            raise ValueError("connection closed early")
        buf += chunk
        if len(buf) > config.MAX_REQUEST_BYTES:
            raise ValueError("request too large")

    lines = buf.split(b"\r\n\r\n", 1)[0].split(b"\r\n")
    parts = lines[0].decode().split(" ")
    if len(parts) < 2:
        raise ValueError("malformed request line")
    method, path = parts[0].upper(), parts[1]
    path = path.split("?", 1)[0]
    if len(path) > 1 and path.endswith("/"):
        path = path[:-1]

    headers = {}
    for line in lines[1:]:
        if b":" in line:
            key, value = line.split(b":", 1)
            headers[key.decode().strip().lower()] = value.decode().strip()
    return method, path, headers


def token_ok(headers):
    """Compare in constant time so the token cannot be guessed byte by byte."""
    supplied = headers.get(config.AUTH_HEADER, "")
    expected = secrets.API_TOKEN
    if len(supplied) != len(expected):
        return False
    mismatch = 0
    for a, b in zip(supplied, expected):
        mismatch |= ord(a) ^ ord(b)
    return mismatch == 0


# --- Route handlers ---------------------------------------------------------


def door_snapshot(now):
    # No "door" key: there is no sensor, so any value here would be a guess
    # presented as a fact. "moving" is an honest timer, not a measurement.
    return {
        "moving": now < _moving_until,
        "uptime_s": now // 1000,
    }


def handle_health(now, headers):
    return 200, {"ok": True, "uptime_s": now // 1000}


def handle_status(now, headers):
    payload = door_snapshot(now)
    payload.update(
        {
            "ok": True,
            "rssi": rssi(),
            "ip": ip_address(),
            "ssid": secrets.WIFI_SSID,
            "dry_run": config.DRY_RUN,
            "relay_ready": relay.ready(now),
            "reset_cause": RESET_CAUSES.get(machine.reset_cause(), "unknown"),
            "free_mem": gc.mem_free(),
        }
    )
    return 200, payload


def handle_log(now, headers):
    return 200, {"ok": True, "events": log.entries()}


def handle_toggle(now, headers):
    """Pulse the relay. The opener decides what that means.

    There is deliberately no /open or /close. Without a door sensor this
    device cannot tell an open door from a closed one, so a "close" command
    would be a coin flip that opens the garage half the time. One button, the
    same one that is on the wall.
    """
    global _moving_until
    if not relay.pulse(now, "toggle"):
        return 429, {"ok": False, "error": "relay busy, try again shortly"}
    _moving_until = now + config.TRAVEL_MS
    payload = door_snapshot(now)
    payload.update({"ok": True, "action": "pulsed", "dry_run": config.DRY_RUN})
    return 200, payload


# path -> (method, handler, auth_required)
ROUTES = {
    "/health": ("GET", handle_health, False),
    "/status": ("GET", handle_status, False),
    "/log": ("GET", handle_log, False),
    "/toggle": ("POST", handle_toggle, True),
}


def dispatch(conn, addr):
    now = uptime_ms()
    try:
        method, path, headers = read_request(conn)
    except ValueError as exc:
        send_json(conn, 400, {"ok": False, "error": str(exc)})
        return
    except OSError:
        return  # client vanished mid-request

    route = ROUTES.get(path)
    if route is None:
        send_json(
            conn, 404, {"ok": False, "error": "no such endpoint", "path": path}
        )
        return

    want_method, handler, auth_required = route
    if method != want_method:
        send_json(
            conn,
            405,
            {"ok": False, "error": "use %s %s" % (want_method, path)},
        )
        return

    if auth_required and not token_ok(headers):
        log.add("auth_fail", "%s %s from %s" % (method, path, addr[0]), now)
        send_json(
            conn, 401, {"ok": False, "error": "bad or missing auth token"}
        )
        return

    code, payload = handler(now, headers)
    send_json(conn, code, payload)


def serve_socket():
    sock = socket.socket(socket.AF_INET, socket.SOCK_STREAM)
    sock.setsockopt(socket.SOL_SOCKET, socket.SO_REUSEADDR, 1)
    sock.bind(("0.0.0.0", config.HTTP_PORT))
    sock.listen(2)
    sock.setblocking(False)
    return sock


# --- Main loop --------------------------------------------------------------


def main():
    global wdt

    log.add(
        "boot",
        "reset=%s dry_run=%s"
        % (RESET_CAUSES.get(machine.reset_cause(), "?"), config.DRY_RUN),
        uptime_ms(),
    )

    if config.WDT_ENABLED:
        # Started only after the relay pin is already idle, and only after
        # secrets loaded, so a config mistake does not become a boot loop.
        wdt = machine.WDT(0, config.WDT_TIMEOUT_MS)

    wifi_start()
    wifi_connect()

    sock = serve_socket()
    poller = select.poll()
    poller.register(sock, select.POLLIN)
    log.add("http_up", "port %d" % config.HTTP_PORT, uptime_ms())

    next_gc = 0
    while True:
        now = uptime_ms()
        feed()
        relay.poll(now)
        wifi_poll(now)

        # 20 ms is short enough to release the relay within a millisecond or
        # two of the 500 ms mark, and long enough that the loop is not a busy
        # spin.
        for _sock, _event in poller.poll(20):
            conn = None
            try:
                conn, addr = sock.accept()
                conn.settimeout(config.CLIENT_TIMEOUT_S)
                dispatch(conn, addr)
            except OSError:
                pass
            except Exception as exc:  # never let one bad request kill the loop
                log.add("request_error", repr(exc), uptime_ms())
            finally:
                if conn is not None:
                    try:
                        conn.close()
                    except OSError:
                        pass

        if now >= next_gc:
            next_gc = now + 5000
            gc.collect()


try:
    main()
except Exception as exc:
    # Anything unexpected: drop the contact, record why, and let the board
    # restart clean rather than sitting there wedged with the API down.
    relay.safe_off()
    sys.print_exception(exc)
    print("unhandled exception, resetting in 5s")
    time.sleep(5)
    machine.reset()

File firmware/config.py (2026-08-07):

"""Tunable configuration for the garage door controller.

Pin assignments here must stay in sync with the wiring table in CLAUDE.md
and docs/hardware.md.
"""

# --- Safety -----------------------------------------------------------------

# When True the relay pin is never driven; pulses are logged only.
# Leave this True for bench testing, set to False once the relay is wired
# to the opener and you are ready to move the actual door.
DRY_RUN = False

# --- Pins -------------------------------------------------------------------

# Relay trigger. GPIO 5 is a plain GPIO on the ESP32-S3, not a strapping pin.
# NEVER move this to GPIO 0, 3, 45 or 46: those float or glitch during boot
# and would pulse the door on every reset.
RELAY_PIN = 5

# There is no door sensor. This controller pulses the opener's pushbutton and
# nothing else; it cannot report whether the door is open or closed. Knowing
# the door's state is handled out of band, by a camera pointed at the garage.

# Measured on this build's module, a Songle SRD-03VDC-SL-C board with screw
# terminal inputs: IN touched to 3V3 energises the relay, IN to GND does not.
# That makes it active HIGH, which is the less common case for these boards.
#
# Consequence worth knowing: idle is now a LOW pin. Between power-on and the
# moment MicroPython configures GPIO 5, the pin is an undriven input and
# floats. If it floats high enough, the relay can click during boot. Step 4 of
# docs/hardware.md tests exactly this, and the fix is a 10k pull-down resistor
# from GPIO 5 to GND. Do not skip that test.
RELAY_ACTIVE_HIGH = True

# --- Timing -----------------------------------------------------------------

# How long the relay contact stays closed. This emulates a wall-button press.
# Never made longer, and the relay is always released by the main loop.
PULSE_MS = 500

# Ignore new pulse requests while a pulse is in flight, plus this cooldown.
# Stops a double-tap or a retrying client from immediately reversing the door.
COOLDOWN_MS = 2000

# Roughly how long the door takes to travel end to end. Used only to report
# a "moving" hint in /status, meaning "we pulsed recently, so the door is
# probably still travelling". It is a timer, not a measurement, and it does
# not gate anything.
TRAVEL_MS = 15000

# --- Network ----------------------------------------------------------------

HTTP_PORT = 80

# Header carrying the shared secret on state-changing requests.
AUTH_HEADER = "x-auth-token"

# Per-connection socket timeout, seconds. Keep well under WDT_TIMEOUT_MS.
CLIENT_TIMEOUT_S = 5

# Reject oversized requests instead of buffering them.
MAX_REQUEST_BYTES = 2048

# How often to re-check the WiFi link and attempt a reconnect.
WIFI_RETRY_MS = 10000

# --- Watchdog ---------------------------------------------------------------

# Hardware watchdog. If the main loop wedges, the board reboots. A reboot
# leaves the relay pin idle, so it cannot pulse the door.
WDT_ENABLED = True
WDT_TIMEOUT_MS = 20000

# --- Logging ----------------------------------------------------------------

# Number of events kept in the in-memory ring buffer served at /log.
LOG_SIZE = 40

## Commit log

2026-08-07 Remote garage door controller: firmware, tools, enclosure, docs
    An ESP32-S3 and an optocoupler relay that bridge a Linear opener's pushbutton
    terminals for 500 ms, exactly like pressing the wall button. The device is LAN
    only; reaching it from outside the house is a local server's job.
    There is no door sensor, so POST /toggle is the only door command. A camera
    covers door state, and answers the question a reed switch could not: whether
    anyone is standing in the doorway.
    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
    [remote-garage-opener v11_enclosure_base.stl, remote-garage-opener v11_enclosure_lid.stl]
2026-09-24 add remote access via iphone shortcut
    [garage.py]
